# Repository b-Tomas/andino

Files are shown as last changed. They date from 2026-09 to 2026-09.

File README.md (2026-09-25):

# Andino

This is my fork of the [Ekumen-OS/andino](https://github.com/Ekumen-OS/andino) robot, with a few modifications done to accommodate my own needs, mainly the alternative hardware that I bought.

## Hardware

Hardware changes, originally described in [andino_hardware/README.md](andino_hardware/README.md):

| Part_number | Was | Is | Purchase link | Comments |
| :---: | :---: | :---: | :---: | :---: |
| 1 | Raspberry Pi 4 B (4 GB) | Raspberry Pi 5 (8 GB) | [Amazon bundle](https://www.amazon.com/dp/B0D2WYFS23) | Needs a 5 V / 5 A supply. See [Known issues](#known-issues) |
| 7 | 2 x DG01D-E motor with encoder (1:48) | 2 x motor with hall encoder, 12 PPR, 1:90 gearbox | [Amazon](https://www.amazon.com/dp/B0GHYFZ2SQ) | 4320 ticks per wheel rev instead of 585. See [Motors](#motors) |
| 9 | Arduino Nano | Arduino Nano v3 (new bootloader) | [Amazon 3x bundle](https://www.amazon.com/dp/B07G99NNXL) | Uploads at 115200 baud. See [Firmware](#firmware) |
| 13 | Raspi Camera Module V2 (IMX219) | Arducam 8.3MP IMX415 | [Amazon](https://www.amazon.com/dp/B0FG73N2BK) | [Arducam docs](https://docs.arducam.com/Raspberry-Pi-Camera/Native-camera/8.3MP-IMX415/). Needs manual setup, see [Camera](#camera-arducam-imx415) |
| 14 | Battery case | 4-cell battery case | [Amazon 4x bundle](https://www.amazon.com/dp/B07TWD3GRJ) | East to cut one of the bays out. |
| 15 | Batteries | Batteries salvaged from old laptop computers. No protection. | - | Needs a BMS to work safely. |
| - | - | BMS board | [Mercadolibre (AR)](https://www.mercadolibre.com.ar/modulo-proteccion-carga-bateria-litio-3s-40a-12v-18650-bms/up/MLAU184006431) | Still don't know if it works |
| 17 | DC-DC converter | DC-DC converter with USB-C output | [Amazon](https://www.amazon.com/dp/B0BCP86XPY) | Bigger. Needed to cut a hole in the chassis. |
| 19 | Caster wheel | 1-in caster wheels | [Amazon 8x pack](https://www.amazon.com/dp/B09CTSLPCL) | Didn't notice I bought bigger wheels. Need replacing. |

3D model changes:

- `andino_hardware/printing_model/chassis/battery_chassis_custom.{FCStd,3mf}` replaces `battery_chassis.stl`. I redesigned it for my battery holder, BMS board and DC-DC converter.

## Firmware

The new `nanoatmega328new` PlatformIO environment (`andino_firmware/platformio.ini`) flashes the newer Arduino Nano v3 clone at 115200 bps, otherwise at 57600 bps it would time out.

To flash and test the firmware:

```sh
cd andino_firmware
pio run --target upload -e nanoatmega328new
pio device monitor -b 57600 -p /dev/ttyUSB0 --echo --eol CR -f send_on_enter
```

### Motors

- 12 PPR per channel and a 1:90 gearbox. The firmware counts 12 × 4 × 90 = 4320 ticks per wheel rev.
- Open loop at PWM 150, wheels in the air: left ~103 rpm, right ~63 rpm. The right motor is noticeably slower.
- On the first test the right encoder had A/B swapped. Symptom: in closed loop the right PID got positive feedback and pinned at +255, running at full speed whatever the setpoint.

Deadband is about 35-60 PWM.

### PID

The default gains in `andino_firmware/include/andino/app/constants.h` are now kp 20, kd 18, ki 0, ko 100. The originals were 30/10/0/10.

## Software

I decided to run the Andino stack on Ubuntu 24.04 (ROS 2 Jazzy) on the Raspberry Pi 5 that I got. This meant:

- Manually setting up the IMX415 Arducam that I got.
- Skipping some steps of the SBC section of [andino_hardware/README.md](andino_hardware/README.md) that don't apply to this setup.
- Running RViz and the camera viewer from my laptop in Docker.

### SBC setup differences

Followed the SBC section of [andino_hardware/README.md](andino_hardware/README.md) with these changes:

- Skipped installing `arduino`, as I only needed it to flash the micro on my laptop.
- **Raspberry Camera Module V2:** skipped the whole section. The indications are for a legacy stack, which doesn't apply to Ubuntu 24.04 on a Pi 5. Follow [Camera](#camera-arducam-imx415).

### Camera (Arducam IMX415)

Ubuntu 24.04 ships kernel 6.8 and libcamera 0.2. Both are too old for the IMX415 on the Pi 5, which uses Raspberry Pi's PiSP camera pipeline. Arducam's own install script targets Raspberry Pi OS. Don't run it on Ubuntu.

Consider running Andino dockerized and using Raspbian with a newer kernel on the Pi instead.

1-. Device tree overlay:

```sh
sudo cp /boot/firmware/config.txt ~/config.txt.bak
wget -O ~/imx415.dtbo https://raw.githubusercontent.com/raspberrypi/firmware/master/boot/overlays/imx415.dtbo
sudo cp ~/imx415.dtbo /boot/firmware/overlays/
```

Add this under `[all]` in `/boot/firmware/config.txt`, then reboot:

```
dtoverlay=imx415
```

Check: `sudo dmesg | grep -i imx415` should print `Detected IMX415 image sensor`. A kernel update may wipe `/boot/firmware/overlays/`, so keep `~/imx415.dtbo` to copy it back.

2-. Kernel driver: libcamera sets parameters that under the default driver are read-only, producing `Unable to set controls: Permission denied` error lines on every frame and breaking features like auto-exposure. Raspberry Pi's version of the driver builds against 6.8 unchanged:

```sh
# TODO(b-Tomas): de-slop, cite sources
sudo apt install -y linux-headers-$(uname -r)
grep V4L2_CCI /boot/config-$(uname -r)          # expect =m or =y
mkdir -p ~/imx415-rpi && cd ~/imx415-rpi
wget -O imx415.c https://raw.githubusercontent.com/raspberrypi/linux/rpi-6.12.y/drivers/media/i2c/imx415.c
echo 'obj-m += imx415.o' > Makefile
make -C /lib/modules/$(uname -r)/build M=$PWD modules
sudo install -D -m644 imx415.ko /lib/modules/$(uname -r)/updates/imx415.ko
sudo depmod -a
modinfo imx415 | head -1                        # expect .../updates/imx415.ko
sudo reboot
```

**Rebuild the module after every kernel update.**

To undo, delete the file from `updates/` and run `sudo depmod -a`.

3-. libcamera: Build Raspberry Pi's fork:

```sh
# TODO(b-Tomas): de-slop, cite sources
sudo apt install -y git meson ninja-build pkg-config python3-yaml python3-ply python3-jinja2 \
  libyaml-dev libgnutls28-dev libudev-dev libdrm-dev libboost-dev openssl libtiff-dev libevent-dev \
  nlohmann-json3-dev
git clone https://github.com/raspberrypi/libcamera.git ~/libcamera
cd ~/libcamera
meson setup build --buildtype=release \
  -Dpipelines=rpi/pisp -Dipas=rpi/pisp \
  -Dv4l2=enabled -Dcam=enabled -Dgstreamer=disabled -Dtest=false \
  -Dlc-compliance=disabled -Dqcam=disabled -Ddocumentation=disabled -Dpycamera=disabled
ninja -C build -j3
sudo ninja -C build install
sudo ldconfig
```

Check:

```sh
hash -r; which cam                  # /usr/local/bin/cam
cam -l                              # lists imx415
cam -c 1 --capture=5                # 5 frames, no errors
```

4-. camera_ros: Build it from source in the workspace so it links the new libcamera. Don't install `ros-jazzy-camera-ros` from apt. It links Ubuntu's libcamera, which has no IMX415 support.

```sh
cd ~/ws/src
git clone https://github.com/christianrauch/camera_ros.git
cd ~/ws
rosdep install --from-paths src -i -y -r --skip-keys=libcamera
colcon build --packages-select camera_ros
```

Always pass `--skip-keys=libcamera` to `rosdep install` on the robot. Otherwise rosdep installs Ubuntu's libcamera development files.

Not done yet:
- Calibration with `camera_calibration`. Until then `camera_ros` warns that there's no calibration file.
- Trying the Arducam tuning file: `LIBCAMERA_RPI_TUNING_FILE=/usr/local/share/libcamera/ipa/rpi/pisp/imx415_b0569.json`.

### Laptop (RViz, camera view)

I run the visualization tools from my laptop using the repo's Docker setup:

```sh
sudo ufw allow from <robot-ip>
./docker/build.sh --ros_distro jazzy
./docker/run.sh --ros_distro jazzy
```

Inside the container (the repo is mounted):

```sh
cd ~/ws
rosdep install -i -y --rosdistro jazzy --from-paths src
colcon build --symlink-install
source install/setup.bash
ros2 run rqt_image_view rqt_image_view /image_raw/compressed
ros2 launch andino_bringup rviz.launch.py
```

- `andino_bringup/rviz/andino.rviz` uses Fixed Frame `map`, which only exists while SLAM or localization is running. Without it, RViz drops the scans (`discarding message because the queue is full`). For teleop, set Global Options → Fixed Frame to `odom`.
- Answer `y` to the "overwrite the image" prompt when leaving the container. Otherwise the packages `rosdep` installed are lost.
- If no topics show up, check that both machines have the same `ROS_DOMAIN_ID` and that the clocks are in sync (`timedatectl`).

### ROS2

Changes to the ROS packages:

- `andino_description/config/andino/hardware.yaml`: `enc_ticks_per_rev: 4320` (was 585).
- `andino_control/config/andino_controllers.yaml`: `wheel_separation: 0.13`, `wheel_radius: 0.03365` (measured).
- `andino_bringup/launch/camera.launch.py`: `camera_ros` instead of `v4l2_camera`.
- `andino_bringup/package.xml`: `camera_ros` replaces `v4l2_camera`.

Bringup, on the robot:

```sh
cd ~/ws
colcon build
source install/setup.bash
ros2 launch andino_bringup andino_robot.launch.py
```

Check it's running:

```sh
ros2 control list_controllers
ros2 topic hz /scan
ros2 topic hz /image_raw
ros2 topic echo /odom --once
```

Teleop: `ros2 launch andino_bringup teleop_joystick.launch.py`, then hold LB or RB and move the sticks.

## Known issues

- The battery pack hasn't worked yet, working off of a lab power supply.
- The Pi rebooted when the motors started. There was no under-voltage in the kernel log, so it might be a sudden drop. The Pi was already running a but low on voltage (4.89V, `vcgencmd pmic_read_adc EXT5V_V`). For now, the Pi runs from a USB power supply and the motors from a lab power supply.
- The IMU is read by the firmware and by `andino_base::SerialMcu`, but the hardware interface doesn't export it. So there's no `/imu` topic and no sensor fusion. Localization is wheel odometry plus the lidar.

## TODO

- [ ] Calibrate the PID on the ground, with the robot's weight on the wheels.
- [ ] Ingest the PID values via serial and configure them on the ROS side.
- [ ] Fix the power path so the Pi can run from the battery.
- [ ] Expose the IMU through ros2_control.
- [ ] Calibrate the camera.

_Everything below is the upstream README.md from [Ekumen-OS/andino](https://github.com/Ekumen-OS/andino)_

---

<div align="center">

  Logo White

</div>

<div align="center">

  Logo Black

</div>

Andino is a fully open-source diff drive robot designed for educational purposes and low-cost applications.
It is fully integrated with ROS 2 and it is a great base platform to improve skills over the robotics field.
With its open-source design, anyone can modify and customize the robot to suit their specific needs.

<p align="center">
  
</p>

_Note: For videos go to [Media](#selfie-media) section._

## :books: Package Summary

- :rocket: [`andino_bringup`](./andino_bringup): Contains mainly launch files in order to launch all related driver and nodes to be used in the real robot.
- :robot: [`andino_hardware`](./andino_hardware): Contains information about the Andino assembly and hardware parts.
- :ledger: [`andino_description`](./andino_description): Contains the URDF description of the robot.
- :hammer_and_pick: [`andino_firmware`](./andino_firmware): Contains the code be run in the microcontroller for interfacing low level hardware with the SBC.
- :gear: [`andino_base`](./andino_base): [ROS Control hardware interface](https://control.ros.org/master/doc/ros2_control/hardware_interface/doc/writing_new_hardware_interface.html) is implemented.
- :control_knobs: [`andino_control`](./andino_control/): It launches the [`controller_manager`](https://control.ros.org/humble/doc/ros2_control/controller_manager/doc/userdoc.html) along with the [ros2 controllers](https://control.ros.org/master/doc/ros2_controllers/doc/controllers_index.html): [diff_drive_controller](https://control.ros.org/master/doc/ros2_controllers/diff_drive_controller/doc/userdoc.html) and the [joint_state_broadcaster](https://control.ros.org/master/doc/ros2_controllers/joint_state_broadcaster/doc/userdoc.html).
- :world_map: [`andino_slam`](./andino_slam/): Provides support for SLAM with your `andino` robot.
- :compass: [`andino_navigation`](./andino_navigation/): Navigation stack based on `nav2`.

## :paperclips: Related projects

Projects built upon Andino! :rocket:

- :rocket: [`andino_ansible_config`](https://github.com/garyservin/andino_ansible_config): (**Thanks @garyservin !**): Ansible configuration to easily setup an Andino robot.
- :computer: [`andino_gz`](https://github.com/Ekumen-OS/andino_gz): [Gazebo](https://gazebosim.org/home)(non-classic)-based simulation of the `andino` robot.
- :lady_beetle: [`andino_webots`](https://github.com/Ekumen-OS/andino_webots): [Webots](https://github.com/cyberbotics/webots)-based simulation of the Andino robot fully integrated with ROS 2.
- :joystick: [`andino_o3de`](https://github.com/Ekumen-OS/andino_o3de): [O3DE](https://o3de.org/)-based simulation of the Andino robot.
- :green_circle: [`andino_isaac`](https://github.com/Ekumen-OS/andino_isaac): [Isaac Sim](https://docs.omniverse.nvidia.com/isaacsim/latest/index.html)-based simulation of the Andino robot.
- :m: [`andino_mujoco`](https://github.com/Ekumen-OS/andino_mujoco): [MuJoCo](https://mujoco.org/)-based simulation of the Andino robot.
- :robot: [`andino_rmf`](https://github.com/Ekumen-OS/andino_rmf): [OpenRMF](https://www.open-rmf.org/) integration of Andino simulation.
- :test_tube: [`andino_integration_tests`](https://github.com/Ekumen-OS/andino_integration_tests): Extension to the Andino robot showing how to build integration tests.
- :framed_picture: [`andino_lichtblick`](https://github.com/Ekumen-OS/andino_lichtblick): [Lichtblick](https://github.com/lichtblick-suite/lichtblick/) integration with Andino for web-based visualization.
- :crab: [`andino-rs`](https://github.com/Ekumen-OS/andino-rs): Rustacean version of *andino* robot. It also provides integration with [*dora*](https://github.com/dora-rs/dora) framework for both real and simulated *andino*.
- :nerd_face: [`robotics_essentials_ros2`](https://github.com/henki-robotics/robotics_essentials_ros2): ROS 2 Essentials material for robotic course at [*University of Eastern Finland*](https://www.uef.fi/en).

## :busts_in_silhouette: Community

[](https://discord.gg/tHhH32CTHu) Join our Discord and contribute to the community!

## :pick: Robot Assembly

Visit [`andino_hardware`](./andino_hardware/) for assembly instructions.

## :mechanical_arm: Installation

Remember to first go over the assembly instructions at [`andino_hardware`](./andino_hardware/)!

### Platforms

- ROS 2:
  - Humble Hawksbill
  - Jazzy Jalisco
- OS:
  - Ubuntu 22.04 Jammy Jellyfish (Humble)
  - Ubuntu 24.04 Noble Numbat (Jazzy)
  - Ubuntu Mate 22.04 / Ubuntu Server 24.04 (On real robot e.g: Raspberry Pi 4B)

### Via ansible

See [`andino_ansible_config`](https://github.com/garyservin/andino_ansible_config): This repository contains Ansible configurations for managing and automating the setup and configuration of an Andino robot.

### Build from Source

#### Dependencies

1. Install ROS 2: [Humble](https://docs.ros.org/en/humble/Installation/Ubuntu-Install-Debians.html) or [Jazzy](https://docs.ros.org/en/jazzy/Installation/Ubuntu-Install-Debs.html)
2. Install [colcon](https://colcon.readthedocs.io/en/released/user/installation.html)

#### colcon workspace

Packages here provided are colcon packages. As such a colcon workspace is expected:

1. Create colcon workspace

```
mkdir -p ~/ws/src
```

2. Clone this repository in the `src` folder

```
cd ~/ws/src
```

```
git clone https://github.com/Ekumen-OS/andino.git
```

3. Install dependencies via `rosdep`

```
cd ~/ws
```

```
rosdep install --from-paths src --ignore-src -i -y
```

4. Build the packages

```
colcon build
```

5. Finally, source the built packages
   If using `bash`:

```
source install/setup.bash
```

`Note`: Whether your are installing the packages in your dev machine or in your robot the procedure is the same. Remember to go over the assembly instructions first.

### Install the binaries

The packages have been also released via ROS package manager system for the Humble and Jazzy distros. You can check them [here](https://repo.ros2.org/status_page/ros_humble_default.html?q=andino) (Humble) and [here](https://repo.ros2.org/status_page/ros_jazzy_default.html?q=andino) (Jazzy).

These packages can be installed using `apt` (e.g: `sudo apt install ros-humble-andino-description` or `sudo apt install ros-jazzy-andino-description`) or using `rosdep`.

## :rocket: Usage

### Robot bringup

`andino_bringup` contains launch files that concentrates the process that brings up the robot.

After installing and sourcing the andino's packages simply run.

```
ros2 launch andino_bringup andino_robot.launch.py
```

This launch files initializes the differential drive controller and brings ups the system to interface with ROS.
By default sensors like the camera and the lidar are initialized. This can be disabled via arguments and manage each initialization separately. See `ros2 launch andino_bringup andino_robot.launch.py -s ` for checking out the arguments.

- include_rplidar: `true` as default.
- include_camera: `true` as default.

After the robot is launched, use `ROS 2 CLI` for inspecting environment.
For example, by doing `ros2 topic list` the available topics can be displayed:

    /camera_info
    /cmd_vel
    /image_raw
    /odom
    /robot_description
    /scan
    /tf
    /tf_static

   _Note: Showing just some of them_

### Teleoperation

Launch files for using the keyboard or a joystick for teleoperating the robot are provided.

#### Keyboard

```
ros2 launch andino_bringup teleop_keyboard.launch.py
```
This is similarly to just executing `ros2 run teleop_twist_keyboard teleop_twist_keyboard`.

#### Joystick

Using a joystick for teleoperating is notably better.
You need the joystick configured as explained [here](andino_hardware/README.md#Using-joystick-for-teleoperation).
```
ros2 launch andino_bringup teleop_joystick.launch.py
```

### RViz

Use:

```
ros2 launch andino_bringup rviz.launch.py
```

For starting `rviz2` visualization with a provided configuration.

## :compass: Navigation

The [`andino_navigation`](./andino_navigation/README.md) package provides a navigation stack based on the great [Nav2](https://github.com/ros-planning/navigation2) package.

https://github.com/Ekumen-OS/andino/assets/53065142/29951e74-e604-4a6e-80fc-421c0c6d8fee

Follow the [`andino_navigation`'s README](./andino_navigation/README.md) instructions for bringing up the Navigation stack in the real robot or in the simulation.

## :computer: Simulation



Within the Andino ecosystem simulations on several platforms are provided:
 - [`andino_gz`](https://github.com/Ekumen-OS/andino_gz) - **Recommended**
 - [`andino_webots`](https://github.com/Ekumen-OS/andino_webots)
 - [`andino_o3de`](https://github.com/Ekumen-OS/andino_o3de)
 - [`andino_isaac`](https://github.com/Ekumen-OS/andino_isaac)
 - [`andino_mujoco`](https://github.com/Ekumen-OS/andino_mujoco)

## :selfie: Media

### RVIZ Visualization

https://github.com/Ekumen-OS/andino/assets/53065142/c9878894-1785-4b81-b1ce-80e07a27effd

### Slam

Using the robot for mapping.

https://github.com/Ekumen-OS/andino/assets/53065142/283f4afd-0f9a-4d37-b71f-c9d7b2f3e453

https://github.com/Ekumen-OS/andino/assets/53065142/d73f6053-b422-4334-8f62-029a38799e66

See [`andino_slam`](./andino_slam/) for more information.

## :robot: Share your Andino!

Have you built your `Andino` already? Please go to [`Show & Tell`](https://github.com/Ekumen-OS/andino/discussions/categories/show-and-tell) Discussion and share with us your own version of it.

## :star2: Inspirational sources

This section is dedicated to recognizing and expressing gratitude to the open-source repositories that have served as a source of inspiration for this project. We highly recommend exploring these repositories for further inspiration and learning.

 * [articubot_one](https://github.com/joshnewans/articubot_one)
 * [diffbot](https://github.com/ros-mobile-robots/diffbot)
 * [noah_hardware](https://github.com/GonzaCerv/noah-hardware)
 * [linorobot](https://github.com/linorobot/linorobot2)

## :raised_hands: Contributing

Issues or PRs are always welcome! Please refer to [CONTRIBUTING](CONTRIBUTING.md) doc.

## Code development

Note that a [`Docker`](./docker) folder is provided for easy setting up the workspace.

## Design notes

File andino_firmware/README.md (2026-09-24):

# andino_firmware

Firmware code to be run in the arduino microcontroller for proper control of the motors of the robot.

## Connection

Check `encoder_driver.h` and `motor_driver.h` files to check the expected pins for the connection.

## Installation

### Arduino
In Arduino IDE, go to `tools->Manage Libraries ...` and install:
- "Adafruit BNO055"

Verify and Upload `andino_firmware.ino` to your arduino board.

### PlatformIO
1. Install dependencies `sudo apt-get install python3.10-venv`
2. Install platformio
```
curl -fsSL -o /tmp/get-platformio.py https://raw.githubusercontent.com/platformio/platformio-core-installer/master/get-platformio.py
python3 /tmp/get-platformio.py
```
3. Add platformio to your $PATH:
```
echo "PATH=\"\$PATH:\$HOME/.platformio/penv/bin\"" >> $HOME/.bashrc
source $HOME/.bashrc
```
4. Build and upload the firmware
   - If you're using an arduino uno `pio run --target upload -e uno`
   - If you're using an arduino nano `pio run --target upload -e nanoatmega328` or `pio run --target upload -e nanoatmega328new` for a newer arduino nano v3 with a higher upload baud rate.

## Description

Via `serial` connection (57600 baud) it is possible to interact with the microcontroller. The interface is described in the [commands.h](src/commands.h) file. Here are the most used commands:

 - Get encoder values: `'e'`
 - Set open-loop speed for the motors[pwm] `'o <left> <right>'`
   - Example to move forward full speed: `'o 255 255'`
   - Range `[-255 -> 255]`
 - Set closed-loop speed for the motors[ticks/sec] `'m <left> <right>'`
   - Important!: See the `Test it!` section.
 - Set PID values: `'u <kp> <kd> <ki> <offset>'`

Note: Remember the carriage return character at the end of the message.

## Test it!

A serial port connection must be created at 57600 bauds. You can use the serial monitor from Arduino IDE, a tool like `minicom` or PlatformIO's own serial monitor (for example, using `pio device monitor -b 57600 -p /dev/ttyUSB0 --echo --eol CR -f send_on_enter`).

* Open loop verification:
  - Send `o 255 255` to go full speed
  - Send `o 0 0` to stop it.

* Read the encoders
  - Send `e` to get the encoders values.

* Get the ticks per revolution of your motor.
  - First set the encoders to zero, (reeboting with `r`).
  - Then rotate your motors as many revs you want,(say 10 for example) and then divide the encoder ticks per the number of revs. -> Then you get the ticks per revolution. Save this value, it is calibration for the control loop.

* Closed loop verification
  - Send `m <tps> <tps>` where `tps` stands for `ticks per second`. For example if your motor-encoder system gets 700 ticks per revolution then sending `m 700 700` will rotate both motors at 1 rev per sec. (~3.14rad/sec)

## Commands

| Command | Description | Args | Example | Result |
| --- | --- | --- | --- | --- |
| `a` | Read Analog GPIO pin | pin_number | `a 0` |  |
| `d` | Read encoder digital input value | encoder (0: left, 1: right) channel (0: A, 1: B) | `d 0 0` | `0` or `1` |
| `e` | Get encoder tick values |  | `e` | `<left> <right>` |
| `r` | Reset encoder values |  | `r` |  |
| `m` | Set closed-loop speed for the motors[ticks/sec] | left_tps right_tps | `m 700 700` |  |
| `o` | Set open-loop speed for the motors[pwm] | left_pwm right_pwm | `o 255 255` |  |
| `u` | Set PID values | kp kd ki offset | `u 1.0 0.1 0.01 0` |  |
| `h` | Get if IMU is connected |  | `h` | `0` if not connected, `1` if connected |
| `i` | Get IMU data and encoder tick values |  | `i` | `<left> <right>  <orientation_X> <orientation_Y> <orientation_Z> <orientation_W> <angular_velocity_X> <angular_velocity_Y> <angular_velocity_Z> <linear_acceleration_X> <linear_acceleration_Y> <linear_acceleration_Z>` |

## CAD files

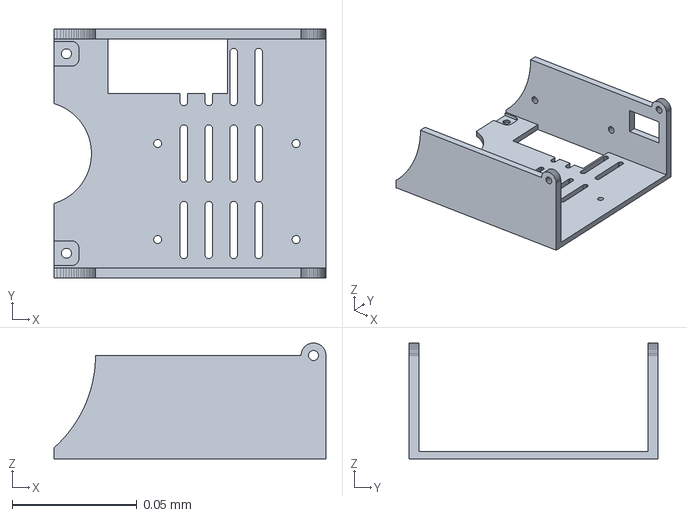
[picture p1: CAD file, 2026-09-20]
andino_hardware/printing_model/chassis/battery_chassis_custom.FCStd
0.109 x 0.1 x 0.0465 mm

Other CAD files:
andino_hardware/printing_model/chassis/battery_chassis_custom.3mf

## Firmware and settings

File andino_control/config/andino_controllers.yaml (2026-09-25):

controller_manager:
  ros__parameters:
    update_rate: 50  # Hz

    diff_controller:
      type: diff_drive_controller/DiffDriveController

    joint_state_broadcaster:
      type: joint_state_broadcaster/JointStateBroadcaster

diff_controller:
  ros__parameters:
    # See https://github.com/ros-controls/ros2_controllers/blob/humble/diff_drive_controller/src/diff_drive_controller_parameter.yaml
    publish_rate: 50.0
    left_wheel_names: ['left_wheel_joint']
    right_wheel_names: ['right_wheel_joint']
    wheels_per_side: 1
    wheel_separation: 0.13 # was: 0.137
    wheel_radius: 0.03365 # was: 0.035
    odom_frame_id: odom
    base_frame_id: base_link
    enable_odom_tf: true
    use_stamped_vel: true

    linear.x.has_velocity_limits: false
    linear.x.has_acceleration_limits: false
    linear.x.has_jerk_limits: false
    linear.x.max_velocity: 0.0
    linear.x.min_velocity: 0.0
    linear.x.max_acceleration: 0.0
    linear.x.min_acceleration: 0.0
    linear.x.max_jerk: 0.0
    linear.x.min_jerk: 0.0

    angular.z.has_velocity_limits: false
    angular.z.has_acceleration_limits: false
    angular.z.has_jerk_limits: false
    angular.z.max_velocity: 0.0
    angular.z.min_velocity: 0.0
    angular.z.max_acceleration: 0.0
    angular.z.min_acceleration: 0.0
    angular.z.max_jerk: 0.0
    angular.z.min_jerk: 0.0

# Commented out as no parameters are passed to this controller:
#
# joint_state_broadcaster:
#   ros__parameters:

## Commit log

2026-09-20 Customize battery_chassis_custom for my holder, BMS board and DC-DC converter
    [battery_chassis_custom.3mf, battery_chassis_custom.FCStd]
2026-09-22 Customize battery_chassis for my holder, BMS board and DC-DC converter (#1)
    [battery_chassis_custom.3mf, battery_chassis_custom.FCStd]
2026-09-24 PID calibration for my motors (1:90 gear ratio) (#3)
    https://www.amazon.com/dp/B0GHYFZ2SQ
2026-09-25 ROS2 stack configuration and fork documentation (#4)
    * Making the robot work
    * Clean up the camera work
    * Updates to hardware measurements
    * Update motor gear ratio
    * README updates
    * Add missing links
    [andino_controllers.yaml, hardware.yaml]
